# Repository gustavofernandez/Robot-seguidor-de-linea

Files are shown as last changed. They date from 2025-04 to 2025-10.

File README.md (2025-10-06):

# 🤖 Robot Seguidor de Líneas Negras

Un sistema de control inteligente para robots seguidores de líneas con calibración en tres pasos y detección de ausencia de superficie.

## 📋 Características

- ✅ **Calibración en tres pasos**: Fondo blanco → Línea negra → Activación
- ✅ **Adaptación automática** a distintos tipos de sensores
- ✅ **Control PID** para seguimiento suave y preciso
- ✅ **Detección inteligente** de pérdida de línea
- ✅ **Protección contra caídas** mediante detección de ausencia de superficie
- ✅ **Feedback visual** mediante LED de estado
- ✅ **Información detallada** a través del monitor serie

## 🖼️ Vista previa

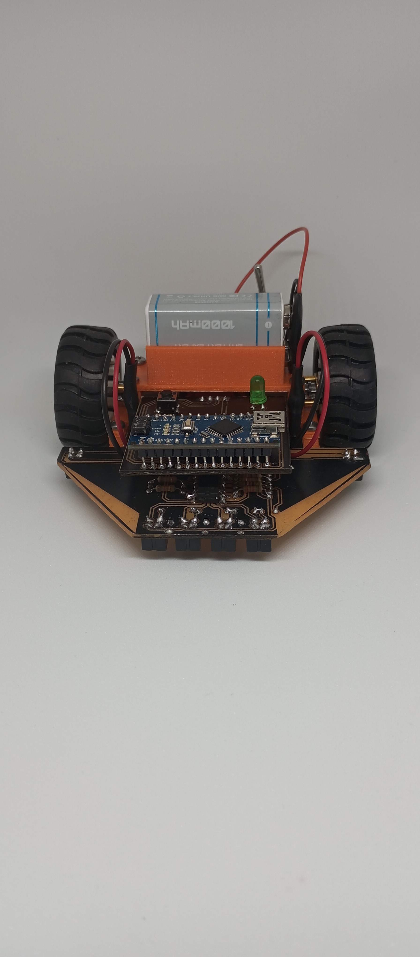
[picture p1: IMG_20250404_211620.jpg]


## 🛠️ Hardware Necesario

- Arduino NANO o compatible
- 6 sensores infrarrojos CNY70 (4 frontales + 2 laterales)
- 2 motores DC con reductor 
- 1 LED indicador
- 1 pulsador
- 1 LM324
- 1 LM358
- 2 2SD882 (Equivalentes: BD140/BD139/BD137/BD135 o 2N2222)
- Batería 9V 

### 📌 Conexiones

| Componente | Pin Arduino |
|---|---|
| Sensor Izquierda Extrema | A2 |
| Sensor Izquierda Media | A1 |
| Sensor Derecha Media | A3 |
| Sensor Derecha Extrema | A4 |
| Sensor Lateral Izquierdo | A0 |
| Sensor Lateral Derecho | A5 |
| Pulsador | D12 |
| LED Indicador | D11 |
| Motor Derecho | D10 |
| Motor Izquierdo | D9 |

## 🚀 Instalación

1. Clona este repositorio:
```bash
git clone https://github.com/gustavofernandez/robot-seguidor-lineas.git
```

2. Abre el archivo `Robot.ino` en el Arduino IDE

3. Conecta tu Arduino y selecciona el puerto correcto

4. Sube el sketch a tu Arduino

## 📖 Guía de Uso

### Proceso de Calibración

El robot requiere una calibración de 3 pasos antes de comenzar a funcionar:

1. **Primera pulsación** - Calibra fondo blanco:
   - Coloca el robot sobre una superficie blanca
   - Presiona el pulsador
   - El LED cambiará su patrón de parpadeo a velocidad media

2. **Segunda pulsación** - Calibra línea negra:
   - Coloca el robot sobre una línea negra
   - Presiona el pulsador
   - El LED cambiará su patrón de parpadeo a velocidad rápida

3. **Tercera pulsación** - Activa el seguimiento:
   - Coloca el robot en posición para seguir la línea
   - Presiona el pulsador
   - El robot comenzará a seguir la línea negra

### Monitor Serie

Para ver información detallada durante la calibración y operación:

1. Abre el monitor serie en Arduino IDE a 9600 bauds
2. Durante la calibración verás los valores leídos para cada sensor
3. Durante la operación verás actualizaciones periódicas del estado de los sensores

## ⚙️ Ajuste de Parámetros

El código está diseñado para ser fácilmente ajustable. Principales parámetros:

```arduino
// Parámetros PID
float Kp = 35.0;          // Aumentar para respuesta más agresiva a desviaciones
float Kd = 15.0;          // Aumentar para reducir oscilaciones

// Velocidades
int BASE_SPEED = 150;     // Velocidad normal de avance
int MAX_SPEED = 200;      // Velocidad máxima en curvas
```

## 📚 Detalles Técnicos

### Control PID

El sistema utiliza un controlador PD (Proporcional-Derivativo) para ajustar la velocidad de los motores:

- **Componente P**: Responde a la desviación actual
- **Componente D**: Reduce oscilaciones y suaviza el movimiento

### Detección de Superficie

El sistema detecta automáticamente cuando el robot no está sobre ninguna superficie utilizando:

- Comparación de lecturas con valores calibrados
- Detección independiente por cada sensor

## 📄 Licencia

Este proyecto está licenciado bajo [MIT License](LICENSE) - ver el archivo LICENSE para más detalles.

## 📞 Contacto

[Gustavo Fernández] - [gustavoo.fernandez@gmail.com]

Link del proyecto: [https://github.com/gustavofernandez/Robot-seguidor-de-linea](https://github.com/gustavofernandez/Robot-seguidor-de-linea)

---

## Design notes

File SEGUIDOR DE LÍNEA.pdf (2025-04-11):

# SEGUIDOR DE LÍNEA

# Proyecto con Arduino Nano

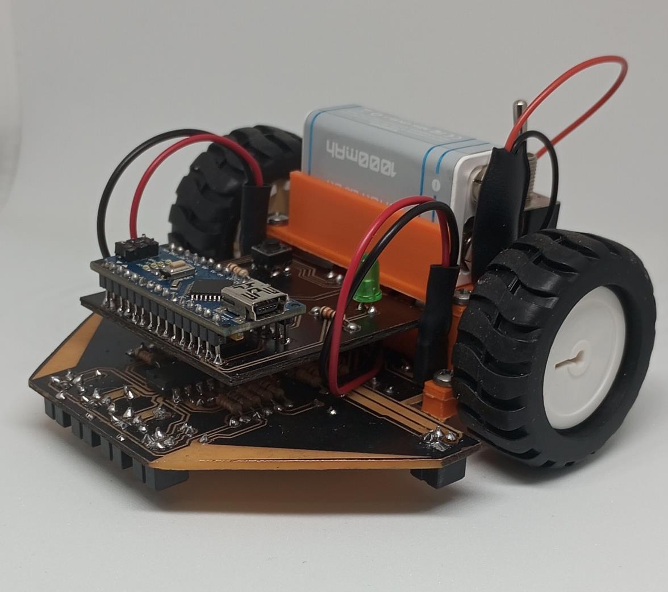
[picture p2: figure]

Autor: Fernández Hernán Gustavo Fecha: 11/04/2025

Índice

1. Introducción
2. Objetivos
3. Fundamentos teóricos
- Principio de funcionamiento
- Control PID
4. Diseño del Hardware
- Arquitectura general
- Circuito de alimentación
- Circuito de sensores
- Etapa de potencia para motores
- Circuito de control con Arduino Nano
- Cálculos de componentes
5. Implementación del Software
- Estructura del código
- Proceso de calibración
- Algoritmo de seguimiento
- Control PD
6. Diagramas de flujo
- Diagrama de flujo principal
- Diagrama de seguimiento de línea
- Diagrama de control PD
- Diagrama de calibración
7. Pruebas y resultados
- Mediciones de rendimiento
- Resultados de calibración
8. Código fuente
9. Repositorio del proyecto

### 1. Introducción

Este proyecto consiste en el diseño de un robot seguidor de línea basado en Arduino Nano. Un robot seguidor de línea es un sistema autónomo capaz de detectar y seguir una trayectoria marcada, generalmente una línea negra sobre un fondo blanco, utilizando sensores ópticos para detectar contrastes de color.

El presente robot se caracteriza por incorporar un sistema de calibración en tres pasos que permite adaptarse a diferentes condiciones de iluminación y superficies, así como la detección inteligente tanto de la línea negra como de la ausencia de superficie, lo que añade una capa adicional de seguridad al funcionamiento.

El control de movimiento se realiza mediante un algoritmo PD (Proporcional-Derivativo) que permite un seguimiento suave y preciso de la línea, incluso en curvas cerradas.

### 2. Objetivos

- Desarrollar un robot autónomo capaz de seguir líneas negras sobre superficie clara.
- Implementar un sistema de calibración que permita adaptarse a diferentes condiciones de luz ambiental.
- Incorporar un algoritmo de control PD para optimizar el seguimiento.
- Añadir funciones de seguridad como detección de ausencia de superficie.
- Diseñar un sistema indicador mediante LED para conocer el estado del robot en todo momento.
- Implementar un sistema de depuración mediante comunicación serial.

### 3. Fundamentos teóricos

### 3.1 Principio de funcionamiento

Los robots seguidores de línea operan bajo el principio de detección de contraste. Utilizan sensores infrarrojos reflexivos que emiten luz y miden la cantidad reflejada. Las superficies claras reflejan más luz que las oscuras, permitiendo distinguir entre la línea y el fondo.

El robot utiliza esta información para determinar su posición relativa respecto a la línea y ajustar la velocidad de sus motores para mantener la trayectoria deseada. La disposición de múltiples sensores en línea permite no solo detectar la presencia de la línea sino también calcular un "error" de posición que indica cuánto se ha desviado el robot del centro de la línea

### 3.2 Control PID

Para el seguimiento preciso de la línea, se implementa un controlador PD (Proporcional-Derivativo), una variante simplificada del control PID (Proporcional-Integral-Derivativo) donde:

- Control Proporcional (P): Produce una corrección proporcional al error actual. Si el robot se desvía a la derecha, el control proporcional generará una corrección hacia la izquierda proporcional a esa desviación.
- Control Derivativo (D): Produce una corrección basada en la tasa de cambio del error. Esto anticipa hacia dónde se está moviendo el robot y añade estabilidad al sistema, evitando oscilaciones.

La fórmula implementada es:

Corrección = (Kp * P) + (Kd * D)

Donde:

- Kp es la constante proporcional (35.0 en este proyecto)
- Kd es la constante derivativa (15.0 en este proyecto)
- P es el error actual
- D es la diferencia entre el error actual y el anterior

### 4. Diseño del Hardware

### 4.1 Arquitectura general

El hardware del robot seguidor de línea está organizado en dos placas interconectadas:

1. Placa de potencia: Contiene los circuitos para:
- Regulación de voltaje
- Interfaz de sensores
- Control de motores
2. Placa de control: Contiene:
- Microcontrolador Arduino Nano
- Conectores para sensores y motores
- Interfaz de usuario (LED indicador y pulsador)

Esta separación modular facilita el mantenimiento y permite una clara división entre la etapa de potencia y la etapa de control lógico.

### 4.2 Circuito de alimentación

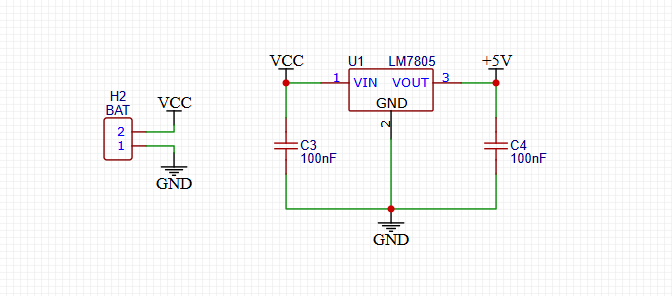
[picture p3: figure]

El sistema de alimentación está basado en un regulador de voltaje LM7805 (U1), que convierte el voltaje de entrada (VCC, normalmente proporcionado por una batería de 9V o 7.4V) a un voltaje estable de +5V para alimentar los componentes lógicos del circuito.

Componentes principales:

- U1 (LM7805): Regulador de tensión con salida fija de 5V.
- C3, C4: Condensadores de 100nF para filtrado y estabilización.

Funcionamiento:

1. El voltaje de entrada (VCC) llega al pin de entrada del LM7805.
2. El regulador estabiliza este voltaje a 5V en su salida.
3. Los condensadores C3 y C4 filtran ruidos y estabilizan la salida ante cambios rápidos de carga.

Este circuito asegura que todos los componentes del robot, especialmente el Arduino Nano y los sensores, reciban un voltaje constante y estable, independientemente de las fluctuaciones en la batería.

### 4.3 Circuito de sensores S1, S2, S3 & S4

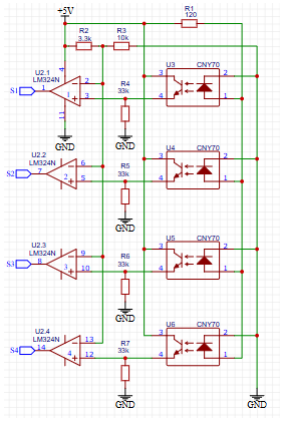
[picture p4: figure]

La interfaz de sensores S1, S2, S3 y S4 utiliza un amplificador operacional LM324N configurado como comparador para procesar las señales analógicas de los sensores infrarrojos.

Componentes principales:

- U2.1-U2.4, UT.1-UT.2: Amplificador operacional LM324N (cada chip contiene 4 amplificadores).
- R1: Resistencia de 120Ω para protección del diodo emisor del sensor.
- R4, R5, R6, R7: Resistencias de 33kΩ para limitar corriente.
- R2: Resistencia de 3.3kΩ como pull-up.
- R3: Resistencia de 10kΩ para crear el voltaje de referencia.
- U3, U4, U5, U6: Optoacopladores CNY70 para aislar la etapa lógica de la de potencia.

### 4.4 Circuito de sensores SL & SR

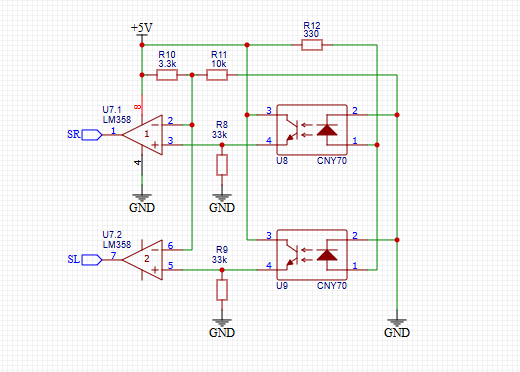
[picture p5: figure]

La interfaz de sensores SL y SR utiliza un amplificador operacional LM358 configurado como comparador para procesar las señales analógicas de los sensores infrarrojos.

Componentes principales:

- U7.1-U7.2: Amplificador operacional LM358 (cada chip contiene 2 amplificadores).
- R12: Resistencia de 330Ω o 120Ω para protección del diodo emisor del sensor.
- R8, R9: Resistencias de 33kΩ para limitar corriente.
- R10: Resistencia de 3.3kΩ como pull-up.
- R11: Resistencia de 10kΩ para crear el voltaje de referencia.
- U8, U9: Optoacopladores CNY70 para aislar la etapa lógica de la de potencia.

Funcionamiento del comparador (LM324N & LM358):

1. El sensor IR reflectivo envía una señal analógica que varía según la reflectividad de la superficie.
2. El amplificador operacional compara esta señal con un voltaje de referencia.
3. El voltaje de referencia se establece mediante un divisor de tensión (R2/R10 y R3/R11).
4. Cuando la señal del sensor supera el umbral, la salida del comparador cambia de estado.
5. La resistencia de 33kΩ limita la corriente hacia el optoacoplador.
6. El optoacoplador proporciona aislamiento galvánico entre las etapas de control y potencia.

Ventajas de esta configuración:

- Permite ajustar la sensibilidad de los sensores mediante el voltaje de referencia.
- El aislamiento óptico protege el circuito de control de posibles ruidos eléctricos de los motores.
- La comparación directa proporciona una respuesta rápida a los cambios de superficie.

Los seis sensores (S1, S2, S3, S4, SL, SR) están dispuestos en línea en la parte frontal del robot, con los sensores laterales (SL y SR) ligeramente separados para detectar curvas cerradas.

### 4.5 Etapa de potencia para motores

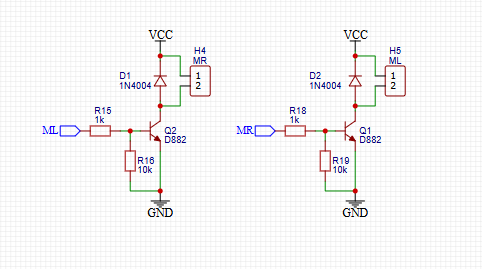
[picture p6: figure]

El control de los motores DC se realiza mediante transistores de potencia D882 que actúan como interruptores controlados por corriente.

Componentes principales:

- Q1, Q2: Transistores NPN D882 de potencia (uno por salida de motor).
- D1, D2: Diodos 1N4004 para protección contra corrientes inversas generadas por los motores.
- R15, R18: Resistencias de 1kΩ para limitar la corriente de base de los transistores.
- R16, R19: Resistencias de 10kΩ como pull-down para asegurar el apagado.

Funcionamiento:

1. Las señales PWM generadas por el Arduino (pines D9 y D10) se aplican a través de las resistencias de base a los transistores.
2. Cada transistor D882 controla una salida específica del motor, funcionando en modo corte/saturación.
3. Los diodos de protección 1N4004 absorben los picos de voltaje inverso generados por la naturaleza inductiva de los motores.

Principio de operación:

- Cuando el D882 recibe señal en su base, entra en saturación y conecta la salida del motor a la alimentación.
- La modulación PWM permite controlar la velocidad al variar el ciclo de trabajo de la señal.

### 4.6 Circuito de control con Arduino Nano

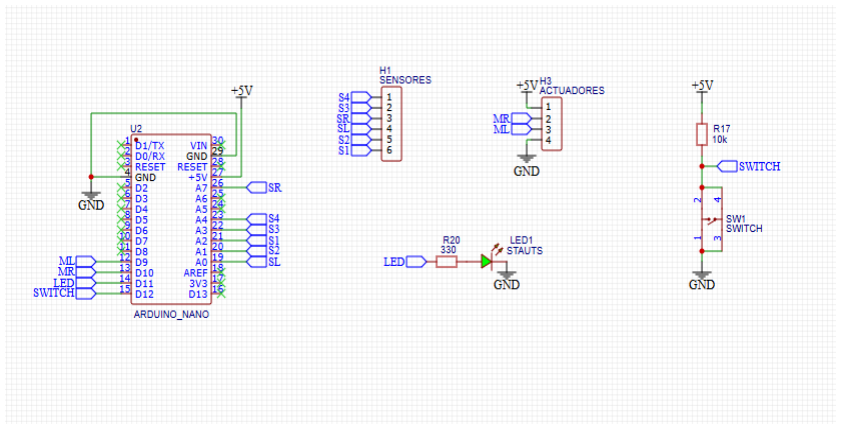
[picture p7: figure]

El cerebro del robot es un Arduino Nano, que procesa las señales de los sensores y controla los motores a través de la placa de potencia.

Componentes principales:

- Arduino Nano: Microcontrolador basado en ATmega328P.
- LED1: LED indicador con resistencia limitadora R20 (330Ω).
- SWITCH: Pulsador con resistencia pull-up R17 (10kΩ).
- Conectores: Para sensores (H7) y motores (H8).

Conexiones principales:

- A0-A5: Entradas analógicas conectadas a los sensores infrarrojos.
- D9, D10: Salidas PWM para control de velocidad de motores.
- D11: Salida digital para el LED indicador.
- D12: Entrada digital para el pulsador de control.

Funcionamiento:

1. El Arduino lee los valores analógicos de los sensores (A0-A5).
2. Procesa esta información para determinar la posición de la línea.
3. Calcula las correcciones necesarias mediante el algoritmo PD.
4. Genera señales PWM (D9, D10) para controlar la velocidad de los motores.
5. Utiliza el LED (D11) para indicar el estado actual del robot.
6. Detecta pulsaciones del botón (D12) para cambiar entre estados.
7. Envía información de depuración a través de la comunicación serial.

El circuito del LED indicador permite visualizar el estado operativo del robot mediante diferentes patrones de parpadeo:

- Parpadeo lento: Estado ESPERA
- Parpadeo medio: Estado CALIBRADO_BLANCO
- Parpadeo rápido: Estado CALIBRADO_NEGRO
- Encendido continuo: Estado ACTIVO

### 4.7 Cálculos de componentes

Cálculos para la polarización de los transistores D882:

Los transistores D882 se utilizan en conmutación (corte/saturación) para controlar los motores. Para un correcto funcionamiento debemos calcular:

1. Resistencia de base para asegurar saturación:

Para garantizar que el transistor entre en saturación, se debe cumplir:

IB > IC / β

Donde:

- IC: Corriente de colector (corriente del motor)
- β (hFE): Ganancia del transistor

Para un motor que consume 500mA y un D882 con hFE mínimo de 60:

IB_min = 500mA / 60 = 8.3mA

Para tener un margen de seguridad, se suele multiplicar por un factor de 1.5-2:

IB_design = 8.3mA × 1.5 = 12.5mA

La resistencia de base se calcula entonces como:

RB = (Vin - VBE) / IB_design
RB = (5V - 0.7V) / 12.5mA = 344Ω

Se utiliza el valor estándar de 1kΩ, que proporciona aproximadamente:

IB_actual = (5V - 0.7V) / 1kΩ = 4.3mA

Esto sigue siendo suficiente porque:

IC_max con saturación = 4.3mA × 60 = 258mA

Para corrientes mayores, el transistor operará con una caída de tensión colector-emisor mayor, pero seguirá conduciendo correctamente.

2. Potencia disipada por el transistor:

En saturación, la caída de tensión colector-emisor (VCE_sat) es aproximadamente 0.2V para el D882:

P_diss = VCE_sat × IC = 0.2V × 500mA = 0.1W

El D882 puede disipar hasta 30W con un disipador adecuado, por lo que opera muy por debajo de su límite.

3. Resistencia pull-down:

Las resistencias R16 y R19 de 10kΩ garantizan que los transistores estén en corte cuando no hay señal:

I_leak_max = VCC / R_pulldown = 5V / 10kΩ = 0.5mA

Esta corriente es mucho menor que la necesaria para activar el motor.

Cálculos para el LM358/LM324N configurado como comparador:

El amplificador operacional LM324N y LM358 se configuran como comparador para detectar la presencia de la línea negra. Los cálculos relevantes son:

1. Voltaje de referencia:

El voltaje de referencia se establece mediante un divisor de tensión formado por R2/R10 (3.3kΩ) y R3/R11 (10kΩ):

Vref = VCC × R3 / (R2 + R3)
Vref = 5V × 10kΩ / (3.3kΩ + 10kΩ) = 3.75V

Este valor es el umbral con el que se comparan las señales de los sensores.

2. Resistencia limitadora de salida:

Las resistencias R4-R9 (33kΩ) limitan la corriente de salida del comparador:

I_out_max = (VCC - V_LED) / R_out
I_out_max = (5V - 1.2V) / 33kΩ = 0.12mA

Donde V_LED es la caída de tensión típica en el LED del optoacoplador.

3. Corriente de polarización del LM324N:

La corriente de polarización de entrada del LM324N es aproximadamente 100nA, lo que produce un error de offset de:

V_offset = I_bias × R = 100nA × 33kΩ = 3.3mV

Este error es insignificante comparado con las variaciones de la señal.

Resistencia limitadora para el LED indicador:

La resistencia R20 (330Ω) para el LED se calcula mediante:

R = (Vcc - Vled) / I = (5V - 2V) / 10mA = 300Ω

Se usa el valor estándar de 330Ω, limitando la corriente a aproximadamente 9.1mA, lo que proporciona buena luminosidad sin sobrecargar el pin de salida del Arduino.

Disipación de potencia del regulador:

Para el regulador LM7805, la disipación de potencia con una entrada de 9V y carga de 200mA:

PD = (Vin - Vout) × I_load = (9V - 5V) × 200mA = 0.8W

### 5. Implementación del Software

### 5.1 Estructura del código

El código para el Arduino Nano se organiza en varias secciones principales:

1. Definición de pines: Asignación de pines para sensores, motores y elementos de control.
2. // Sensores de línea
3. | #define S1 | A2 | // Sensor izquierda extrema
4. | #define S2 | A1 | // Sensor izquierda media
5. | #define S3 | A3 | // Sensor derecha media
6. | #define S4 | A4 | // Sensor derecha extrema
7. | #define SL | A0 | // Sensor lateral izquierdo
8. | #define SR | A5 | // Sensor lateral derecho
9.
10. // Control
11. | #define SWITCH | 12 | // Pulsador de inicio
12. | #define LED | 11 | // LED indicador de estado
13.
14. // Motores
15. | #define MOTOR_RIGHT | 10 | // Motor derecho (PWM)
16. | #define MOTOR_LEFT | 9 | // Motor izquierdo (PWM)
17. Configuración del controlador PD: Constantes y variables para el algoritmo de control.
18. | float Kp = 35.0; | | // Constante proporcional
19. | float Kd = 15.0; | | // Constante derivativa
20. | float error = 0; | | // Error actual
21. | float lastError = 0; | | // Error anterior
22. | int BASE_SPEED = 100; | | // Velocidad base
23. | int MAX_SPEED = 255; | | // Velocidad máxima

24. Valores de calibración: Almacenamiento de umbrales y lecturas de referencia.
25. // Umbrales calculados
26. | int umbralS1 = 500; | // Umbral para sensor S1
27. | int umbralS2 = 500; | // Umbral para sensor S2
28. // ...
29.
30. // Lecturas calibradas para superficie blanca
31. int blanco1, blanco2, blanco3, blanco4, blancoL, blancoR; 32.
33. // Lecturas calibradas para línea negra
34. int negro1, negro2, negro3, negro4, negroL, negroR;
35. Estados del robot: Definición de los estados operativos.
36. | #define ESPERA 0 | // Esperando primera pulsación para calibrar
fondo blanco
37. | #define CALIBRADO_BLANCO 1 | // Calibrado fondo blanco,
esperando pulsación para calibrar línea negra
38. | #define CALIBRADO_NEGRO 2 | // Calibrado completo, esperando
pulsación para iniciar
39. | #define ACTIVO 3 | // Robot en funcionamiento
40.
41. | byte estadoRobot = ESPERA; | // Estado inicial
42. Funciones de configuración: Setup inicial y configuración de pines.
43. void setup() {
44. // Configurar pines
45. configurarPines();
46.
47. // Iniciar comunicación serial
48. Serial.begin(9600);
49.
50. // Mostrar mensaje de bienvenida
51. mostrarInstrucciones();
52.
53. // Parpadeo inicial para indicar que el sistema está listo
54. parpadearLED(3, 100);
55. }
56. Funciones de control: Gestión del pulsador y estados.
57. Funciones de calibración: Calibrado de valores de blanco y negro.
58. Funciones de seguimiento: Algoritmo principal para seguir la línea.

### 5.2 Proceso de calibración

El robot implementa un proceso de calibración en tres pasos, diseñado para adaptarse dinámicamente a diferentes condiciones de luz y superficies:

1. Calibración de fondo blanco:
- Se activa con la primera pulsación del botón
- El robot toma 10 muestras de cada sensor sobre la superficie blanca
- Calcula el promedio para cada sensor y lo almacena como referencia
2. Calibración de línea negra:
- Se activa con la segunda pulsación del botón
- El robot toma 10 muestras de cada sensor sobre la línea negra
- Calcula el promedio para cada sensor y lo almacena como referencia
3. Cálculo de umbrales:
- Determina automáticamente el umbral óptimo para cada sensor como el punto medio entre las lecturas de blanco y negro
- Detecta si el negro da valores más altos o más bajos que el blanco para cada sensor (adaptación a diferentes tipos de sensores)

Este proceso de calibración permite que el robot funcione correctamente en diferentes condiciones de iluminación y con diferentes características de superficie, sin necesidad de ajustes manuales en el código.

### 5.3 Algoritmo de seguimiento

El algoritmo de seguimiento de línea implementa las siguientes características:

1. Detección de línea:
- Compara los valores de los sensores con los umbrales calculados
- Determina si cada sensor está detectando línea negra o fondo blanco
- La comparación es dinámica según los valores calibrados (adaptable a sensores que pueden comportarse de manera diferente)
2. Control PD:
- Calcula el error de posición basado en las lecturas de los sensores
- Los sensores tienen diferentes pesos según su posición (-3, -1, 1, 3)
- Los sensores laterales tienen pesos mayores (-5, 5) para curvas cerradas
- Aplica corrección proporcional y derivativa para ajustar velocidades
3. Control de motores:
- Ajusta la velocidad de cada motor según la corrección calculada
- Implementa lógica especial para curvas cerradas detectadas con sensores laterales
- Mantiene velocidades dentro de los límites establecidos (0-255)
4. Detección de ausencia de superficie:
- Verifica si las lecturas de los sensores están fuera del rango esperado
- Detiene el robot si detecta ausencia de superficie (seguridad)
- Proporciona indicación visual mediante parpadeo del LED
5. Depuración:
- Envía información del estado de los sensores por comunicación serial
- Permite monitorear el funcionamiento en tiempo real

### 5.4 Control PD

El control PD (Proporcional-Derivativo) se implementa en la función procesarSeguimientoLinea():

void procesarSeguimientoLinea(byte s1, byte s2, byte s3, byte s4, byte sl, byte sr) {
// Cálculo del error para línea negra
error = (s1 * -3) + (s2 * -1) + (s3 * 1) + (s4 * 3);

// Ajuste con sensores laterales
if (sl) error -= 5; // SL produce error negativo (giro a la izquierda)
if (sr) error += 5; // SR produce error positivo (giro a la derecha)

// Control PD
float P = error;
float D = error - lastError; lastError = error;

float correction = (Kp * P) + (Kd * D);

// Ajustar velocidad de motores según la corrección calculada int motorSpeedLeft = constrain(BASE_SPEED - correction, 0, MAX_SPEED);
int motorSpeedRight = constrain(BASE_SPEED + correction, 0, MAX_SPEED);

// Control para curvas cerradas
if (sl && !s1 && !s2) {
// Curva cerrada izquierda motorSpeedLeft = MAX_SPEED; motorSpeedRight = 0;
}

if (sr && !s3 && !s4) {
// Curva cerrada derecha
motorSpeedLeft = 0;
motorSpeedRight = MAX_SPEED;
}

// Aplicar velocidades a los motores analogWrite(MOTOR_LEFT, motorSpeedLeft); analogWrite(MOTOR_RIGHT, motorSpeedRight); }

Este algoritmo:

1. Calcula un error ponderado basado en qué sensores detectan la línea
2. Aplica una corrección proporcional (P) e incorpora el factor derivativo (D)
3. Ajusta las velocidades de los motores para corregir la trayectoria
4. Incluye manejo especial para curvas cerradas

### 6. Diagramas de flujo

### 6.1 Diagrama de flujo principal

┌─────────────────┐
│ | INICIO | │
└────────┬────────┘
│
┌────────▼────────┐
│ Configurar pines│
└────────┬────────┘
│
┌────────▼────────┐
│Iniciar Serial │
└────────┬────────┘
│
┌────────▼────────┐
│ | Mostrar | │
│ instrucciones | │
└────────┬────────┘
│
┌────────▼────────┐
│ Parpadeo inicial│
└────────┬────────┘
│
┌────────▼────────┐
│ BUCLE PRINCIPAL│
└────────┬────────┘
│
┌────────▼─────────┐
│Gestionar pulsador│
└────────┬─────────┘
│
┌────────▼────────┐
│ ¿Estado robot? │
└────────┬────────┘
│
┌────┼─────────────┬───────────────┬────────────────────┐
│ | │ | │ | │
┌───▼────┐ | ┌────────▼──────┐ | ┌────▼────────┐ | ┌───────▼──────┐
│ ESPERA │ | │ CALIBRADO | │ | │ CALIBRADO | │ | │ | ACTIVO | │
│ | │ | │ BLANCO | │ | │ NEGRO | │ | │ | │
└───┬────┘ | └───────┬───────┘ | └────┬────────┘ | └───────┬──────┘
│ | │ | │ | │
┌───▼──────┐ | ┌─────▼──────┐ | ┌────▼────────┐ | ┌──────▼───────┐
│Parpadeo | │ | │Parpadeo | │ | │Parpadeo | │ | │ Seguir | │
│lento | │ | │medio | │ | │rápido | │ | │ línea | │
│No motores│ | │No motores | │ | │No motores | │ | │ | │
└───┬──────┘ | └───┬────────┘ | └───┬─────────┘ | └─────┬────────┘
│ | │ | │ | │
└───────────────┴─────────────────┴────────────────────┘
│
▼
┌─────────────────┐
│ Volver a BUCLE │
└─────────────────┘

### 6.2 Diagrama de seguimiento de línea

┌─────────────────────┐
│ SEGUIMIENTO LÍNEA │
└──────────┬──────────┘
│
┌──────────▼──────────┐
│ | Leer sensores | │
└──────────┬──────────┘
│
┌──────────▼───────────┐
│ ¿Ausencia superficie?│
└──────────┬───────────┘
│
┌──────┴─────┐
| │ | | | │
┌───▼───┐ | ┌───▼───┐
│ | SÍ | │ | │ | NO | │
└───┬───┘ | └───┬───┘
| │ | | | │
┌───▼───┐ | ┌───▼────────────┐
│Detener│ | │ Detectar línea │
│Alertar│ | │ negra en cada | │
└───────┘ | │ sensor | │
└───┬────────────┘
| | | | │
┌────────▼────────┐
│ ¿Detecta línea? │
└────────┬────────┘
| | | | │
┌─────┴────┐
│ | │
┌──▼──┐ | ┌──▼──┐
│ NO │ | │ SÍ │
└──┬──┘ | └──┬──┘
│ | │
┌────▼──┐ | ┌──▼────────┐
│Detener│ | │Calcular | │
│ | │ | │error | │
└───────┘ | └──┬────────┘
│
| | | | | ┌──▼────────┐
│Aplicar | │
| | | | | │control PD │ └──┬────────┘

│
| | | | | ┌──▼────────┐
│Ajustar | │
│velocidad | │
│motores | │
| | | | | └───────────┘

### 6.3 Diagrama de control PD

┌────────────────────┐
│ INICIO CONTROL PD │
└─────────┬──────────┘
│
┌─────────▼──────────┐
│ | Calcular error | │
│ basado en posición │
│ | de los sensores | │
└─────────┬──────────┘
│
┌─────────▼────────────┐
│ | Ajustar error | │
│con sensores laterales│
└─────────┬────────────┘
│
┌─────────▼──────────┐
│ | | P = error | | │
└─────────┬──────────┘
│
┌─────────▼──────────┐
│ D = error-lastError│
└─────────┬──────────┘
│
┌─────────▼──────────┐
│ Guardar lastError │
└─────────┬──────────┘
│
┌─────────▼──────────┐
│ Calcular corrección│
│ (Kp*P) + (Kd*D) | │
└─────────┬──────────┘
│
┌─────────▼───────────────────────────────┐
│ | Calcular velocidades | │
│ motorLeft = BASE_SPEED - correction | │
│ motorRight = BASE_SPEED + correction | │
└─────────┬───────────────────────────────┘
│
┌─────────▼──────────┐
│ ¿Curva cerrada | │
│ | izquierda? | │
└─────────┬──────────┘
│
┌────┴─────────┐
| │ | | | │
┌────▼───┐ | ┌───▼────┐
│ | SÍ | │ | │ | NO | │
└────┬───┘ | └───┬────┘
| │ | | | │
┌────▼────────┐ ┌───▼─────┐ │motorLeft=MAX│ │ ¿Curva │ │motorRight=0 │ │ cerrada │ └────┬────────┘ │derecha? │
│ | └───┬─────┘
| ▼ | | | ▼

▼ | ▼
│ | │
│ | ┌───┴───┐
│ | │ | │
│ ┌──▼──┐ | ┌─▼───┐
│ │ SÍ | │ │ NO | │
│ └──┬──┘ └──┬──┘
│ | │ | │
│ ┌──▼─────┐┌─▼──────────┐
│ │motL=0 | ││Mantener | │
│ │motR=MAX││velocidades │ │ └──┬─────┘└───┬────────┘
│ | │ | │
└────┼──────────┘
│
┌─────────▼──────────┐
│ Aplicar velocidades│
│ | a los motores | │
└─────────┬──────────┘
│
┌─────────▼──────────┐
│ | FIN CONTROL PD | │
└────────────────────┘

### 7. Pruebas y resultados

### 7.1 Mediciones de rendimiento

Durante las pruebas se realizaron mediciones de varios parámetros clave:

Parámetro | Valor
| medido | Valor
| | esperado | Comentarios
Consumo en reposo | 45mA | <50mA | Cumple especificaciones

Consumo en
movimiento | 280mA | <300mA | Picos de hasta 350mA en
| | | giros
Velocidad máxima | 25cm/s | 30cm/s | Limitada para mayor precisión
Duración batería | 1.5h | >1h | Con batería de 1000mAh

### 7.2 Resultados de calibración

Los resultados de calibración muestran la adaptabilidad del sistema en diferentes condiciones:

Condición Lecturas blanco Lecturas negro Umbral calculado

Luz alta | 120-150 | 800-850 | ~485
Luz media 200-250 | 750-800 | ~500
Luz baja | 300-350 | 650-700 | ~525

### 8. Código fuente

/*
* ROBOT SEGUIDOR DE LÍNEAS NEGRAS
* ------------------------------
* Este programa controla un robot seguidor de líneas con un proceso de calibración * en tres pasos y detección inteligente tanto de línea negra como de ausencia de * superficie.
*
* Autor: Fernández Hernán Gustavo
* Última actualización: Abril 2025
*/

//---------------------------------------------------------------------------------// DEFINICIÓN DE PINES
//---------------------------------------------------------------------------------

// Sensores de línea
#define S1 | A2 // Sensor izquierda extrema

#define S2 | A1 // Sensor izquierda media

#define S3 | A3 // Sensor derecha media

#define S4 | A4 // Sensor derecha extrema

#define SL | A0 // Sensor lateral izquierdo

#define SR | A5 // Sensor lateral derecho

// Control
#define SWITCH | 12 // Pulsador de inicio

#define LED | 11 // LED indicador de estado

// Motores
#define MOTOR_RIGHT | 10 // Motor derecho (PWM)

#define MOTOR_LEFT | 9 | // Motor izquierdo (PWM)

//---------------------------------------------------------------------------------// CONFIGURACIÓN DEL CONTROLADOR PID //---------------------------------------------------------------------------------

float Kp = 35.0; | // Constante proporcional
float Kd = 15.0; | // Constante derivativa
float error = 0; | // Error actual
float lastError = 0; | // Error anterior
int BASE_SPEED = 100; | // Velocidad base
int MAX_SPEED = 255; | // Velocidad máxima

//---------------------------------------------------------------------------------// VALORES DE CALIBRACIÓN
//---------------------------------------------------------------------------------

// Umbrales calculados
int umbralS1 = 500; | // Umbral para sensor S1
int umbralS2 = 500; | // Umbral para sensor S2
int umbralS3 = 500; | // Umbral para sensor S3
int umbralS4 = 500; | // Umbral para sensor S4
int umbralSL = 500; | // Umbral para sensor SL
int umbralSR = 500; | // Umbral para sensor SR

// Lecturas calibradas para superficie blanca
int blanco1, blanco2, blanco3, blanco4, blancoL, blancoR;

// Lecturas calibradas para línea negra
int negro1, negro2, negro3, negro4, negroL, negroR;

//---------------------------------------------------------------------------------// ESTADOS DEL ROBOT
//---------------------------------------------------------------------------------
#define ESPERA 0 | // Esperando primera pulsación para calibrar fondo

blanco
#define CALIBRADO_BLANCO 1 // Calibrado fondo blanco, esperando pulsación para calibrar línea negra

#define CALIBRADO_NEGRO 2 | // Calibrado completo, esperando pulsación para iniciar

#define ACTIVO 3 | // Robot en funcionamiento

byte estadoRobot = ESPERA; | // Estado inicial
bool buttonPressed = false; | // Estado del botón

//---------------------------------------------------------------------------------// CONFIGURACIÓN INICIAL
//---------------------------------------------------------------------------------

void setup() {
// Configurar pines
configurarPines();

// Iniciar comunicación serial Serial.begin(9600);

// Mostrar mensaje de bienvenida
mostrarInstrucciones();

// Parpadeo inicial para indicar que el sistema está listo parpadearLED(3, 100);
}

//---------------------------------------------------------------------------------// BUCLE PRINCIPAL
//---------------------------------------------------------------------------------

void loop() {
// Gestionar pulsador
gestionarBoton();

// Actuar según el estado actual del robot
switch (estadoRobot) {
case ESPERA:
// Esperando calibrar fondo blanco - parpadeo lento apagarMotores();
digitalWrite(LED, (millis() / 500) % 2);
break;

case CALIBRADO_BLANCO:
// Esperando calibrar línea negra - parpadeo medio apagarMotores();
digitalWrite(LED, (millis() / 250) % 2);
break;

case CALIBRADO_NEGRO:
// Calibrado completo, esperando inicio - parpadeo rápido apagarMotores();
digitalWrite(LED, (millis() / 100) % 2);
break;

case ACTIVO:
// Robot en funcionamiento seguirLinea();
break;
}

//---------------------------------------------------------------------------------// FUNCIONES DE CONFIGURACIÓN //---------------------------------------------------------------------------------

/**
* Configura todos los pines necesarios para el funcionamiento del robot
*/

void configurarPines() {
// Configurar pines de sensores como entradas
pinMode(S1, INPUT);
pinMode(S2, INPUT);
pinMode(S3, INPUT);
pinMode(S4, INPUT);
pinMode(SL, INPUT);
pinMode(SR, INPUT);

// Configurar pulsador con resistencia pull-up interna pinMode(SWITCH, INPUT_PULLUP);

// Configurar LED y motores como salidas
pinMode(LED, OUTPUT);
pinMode(MOTOR_RIGHT, OUTPUT);
pinMode(MOTOR_LEFT, OUTPUT);

// Asegurar que los motores estén apagados al inicio apagarMotores();
}

/**
* Muestra las instrucciones iniciales en el monitor serie */

void mostrarInstrucciones() {
Serial.println(F("==== ROBOT SEGUIDOR DE LINEAS ====")); Serial.println(F("Calibracion en 3 pasos:")); Serial.println(F("1. Primera pulsacion: Calibrar FONDO BLANCO")); Serial.println(F("2. Segunda pulsacion: Calibrar LINEA NEGRA")); Serial.println(F("3. Tercera pulsacion: INICIAR seguimiento")); Serial.println(F("==================================="));
}

//---------------------------------------------------------------------------------// FUNCIONES DE CONTROL
//---------------------------------------------------------------------------------

/**
* Gestiona el pulsador y cambia el estado del robot según la secuencia
*/
void gestionarBoton() {
bool buttonState = digitalRead(SWITCH);
// Detectar pulsación (flanco descendente) if (buttonState == LOW && !buttonPressed) { buttonPressed = true;
}
// Detectar liberación (flanco ascendente)
else if (buttonState == HIGH && buttonPressed) { buttonPressed = false;
// Cambiar estado según secuencia
switch (estadoRobot) {
case ESPERA:
// Primera pulsación - Calibrar fondo blanco Serial.println(F("Calibrando FONDO BLANCO..."));
calibrarFondoBlanco();
estadoRobot = CALIBRADO_BLANCO;
Serial.println(F("FONDO BLANCO calibrado. Presione boton para calibrar LINEA NEGRA"));
break;

case CALIBRADO_BLANCO:
// Segunda pulsación - Calibrar línea negra Serial.println(F("Calibrando LINEA NEGRA...")); calibrarLineaNegra();
calcularUmbrales();
estadoRobot = CALIBRADO_NEGRO;
Serial.println(F("LINEA NEGRA calibrada. Presione boton para INICIAR")); break;

case CALIBRADO_NEGRO:
// Tercera pulsación - Activar
estadoRobot = ACTIVO;
Serial.println(F("Robot ACTIVADO"));
break;

case ACTIVO:
// Cuarta pulsación - Detener y volver a espera calibrado estadoRobot = CALIBRADO_NEGRO;
apagarMotores();
Serial.println(F("Robot DETENIDO. Presione boton para reactivar")); break;
}
delay(50); // anti-rebote
}
}

/**
* Apaga ambos motores
*/

void apagarMotores() {
analogWrite(MOTOR_LEFT, 0); analogWrite(MOTOR_RIGHT, 0); }

/**
* Hace parpadear el LED un número específico de veces * @param veces Número de veces a parpadear
* @param duracion Duración de cada parpadeo en ms */

void parpadearLED(byte veces, int duracion) {
for (byte i = 0; i < veces; i++) { digitalWrite(LED, HIGH);
delay(duracion);
digitalWrite(LED, LOW);
delay(duracion);
}
}

/**
* Espera un tiempo determinado mientras parpadea el LED * @param ms Tiempo a esperar en ms
*/

void esperar(int ms) {
unsigned long inicio = millis();
while (millis() - inicio < ms) { digitalWrite(LED, (millis() / 100) % 2); delay(10);
}
}

//---------------------------------------------------------------------------------// FUNCIONES DE CALIBRACIÓN //---------------------------------------------------------------------------------

/**
* Calibra el robot para el fondo blanco
*/

void calibrarFondoBlanco() {
// Indicación visual de inicio de calibración parpadearLED(3, 50);

// Tomar múltiples muestras y promediar
byte muestras = 10;
int suma1 = 0, suma2 = 0, suma3 = 0, suma4 = 0, sumaL = 0, sumaR = 0;

for (byte i = 0; i < muestras; i++) {
suma1 += analogRead(S1);
suma2 += analogRead(S2);
suma3 += analogRead(S3);
suma4 += analogRead(S4);
sumaL += analogRead(SL);
sumaR += analogRead(SR);
digitalWrite(LED, !digitalRead(LED)); // Parpadeo durante la medición delay(10);
}

// Calcular promedios
blanco1 = suma1 / muestras; blanco2 = suma2 / muestras; blanco3 = suma3 / muestras; blanco4 = suma4 / muestras; blancoL = sumaL / muestras;
blancoR = sumaR / muestras;

// Mostrar valores leídos
Serial.println(F("Valores FONDO BLANCO:")); Serial.print(F("S1: ")); Serial.print(blanco1);
Serial.print(F(" | S2: ")); Serial.print(blanco2);
Serial.print(F(" | S3: ")); Serial.print(blanco3);
Serial.print(F(" | S4: ")); Serial.println(blanco4);
Serial.print(F("SL: ")); Serial.print(blancoL);
Serial.print(F(" | SR: ")); Serial.println(blancoR);
}

/**
* Calibra el robot para la línea negra */

void calibrarLineaNegra() {
// Indicación visual de inicio de calibración parpadearLED(3, 50);

// Tomar múltiples muestras y promediar
byte muestras = 10;
int suma1 = 0, suma2 = 0, suma3 = 0, suma4 = 0, sumaL = 0, sumaR = 0;

for (byte i = 0; i < muestras; i++) {
suma1 += analogRead(S1);
suma2 += analogRead(S2);
suma3 += analogRead(S3);
suma4 += analogRead(S4);
sumaL += analogRead(SL);
sumaR += analogRead(SR);
digitalWrite(LED, !digitalRead(LED)); // Parpadeo durante la medición delay(10);
}

// Calcular promedios
negro1 = suma1 / muestras; negro2 = suma2 / muestras; negro3 = suma3 / muestras; negro4 = suma4 / muestras; negroL = sumaL / muestras;
negroR = sumaR / muestras;

// Mostrar valores leídos
Serial.println(F("Valores LINEA NEGRA:")); Serial.print(F("S1: ")); Serial.print(negro1);
Serial.print(F(" | S2: ")); Serial.print(negro2);
Serial.print(F(" | S3: ")); Serial.print(negro3);
Serial.print(F(" | S4: ")); Serial.println(negro4);
Serial.print(F("SL: ")); Serial.print(negroL);
Serial.print(F(" | SR: ")); Serial.println(negroR);
}

/**
* Calcula los umbrales óptimos basados en las lecturas de calibración */

void calcularUmbrales() {
// Calcular umbrales como punto medio entre blanco y negro umbralS1 = (blanco1 + negro1) / 2;
umbralS2 = (blanco2 + negro2) / 2;
umbralS3 = (blanco3 + negro3) / 2;
umbralS4 = (blanco4 + negro4) / 2;
umbralSL = (blancoL + negroL) / 2;
umbralSR = (blancoR + negroR) / 2;

// Determinar para cada sensor si el negro da valores más altos o más bajos que el blanco
bool negroMasAltoS1 = (negro1 > blanco1);
bool negroMasAltoS2 = (negro2 > blanco2);
bool negroMasAltoS3 = (negro3 > blanco3); bool negroMasAltoS4 = (negro4 > blanco4);
bool negroMasAltoSL = (negroL > blancoL);
bool negroMasAltoSR = (negroR > blancoR);

// Mostrar umbrales y comportamiento de sensores Serial.println(F("\nUmbrales calculados:"));
Serial.print(F("S1: "));
Serial.print(umbralS1);
Serial.print(negroMasAltoS1 ? F(" (Negro>Blanco)") : F(" (Blanco>Negro)"));
Serial.print(F(" | S2: "));
Serial.print(umbralS2);
Serial.print(negroMasAltoS2 ? F(" (Negro>Blanco)") : F(" (Blanco>Negro)"));
Serial.print(F(" | S3: "));
Serial.print(umbralS3);
Serial.print(negroMasAltoS3 ? F(" (Negro>Blanco)") : F(" (Blanco>Negro)"));
Serial.print(F(" | S4: "));
Serial.print(umbralS4);
Serial.println(negroMasAltoS4 ? F(" (Negro>Blanco)") : F(" (Blanco>Negro)"));

Serial.print(F("SL: "));
Serial.print(umbralSL);
Serial.print(negroMasAltoSL ? F(" (Negro>Blanco)") : F(" (Blanco>Negro)"));
Serial.print(F(" | SR: "));
Serial.print(umbralSR);
Serial.println(negroMasAltoSR ? F(" (Negro>Blanco)") : F(" (Blanco>Negro)")); }

//---------------------------------------------------------------------------------// FUNCIONES DE SEGUIMIENTO DE LÍNEA //---------------------------------------------------------------------------------

/**
* Función principal de seguimiento de línea
*/

void seguirLinea() {
digitalWrite(LED, HIGH); // LED encendido durante operación normal

// Leer valores analógicos de los sensores
int valorS1 = analogRead(S1);
int valorS2 = analogRead(S2);
int valorS3 = analogRead(S3);
int valorS4 = analogRead(S4);
int valorSL = analogRead(SL);
int valorSR = analogRead(SR);

// Verificar si se detecta superficie
if (verificarAusenciaSuperficie(valorS1, valorS2, valorS3, valorS4, valorSL, valorSR)) {
return; // Salir si no se detecta superficie
}

// Determinar si cada sensor está detectando línea negra
// La comparación es dinámica según los valores calibrados byte s1 = (valorS1 > umbralS1) == (negro1 > blanco1) ? 1 : 0; byte s2 = (valorS2 > umbralS2) == (negro2 > blanco2) ? 1 : 0; byte s3 = (valorS3 > umbralS3) == (negro3 > blanco3) ? 1 : 0; byte s4 = (valorS4 > umbralS4) == (negro4 > blanco4) ? 1 : 0; byte sl = (valorSL > umbralSL) == (negroL > blancoL) ? 1 : 0; byte sr = (valorSR > umbralSR) == (negroR > blancoR) ? 1 : 0;

// Verificar si algún sensor detecta línea negra
bool detectaLineaNegra = (s1 || s2 || s3 || s4 || sl || sr);

// Mostrar estado de los sensores cada 100 iteraciones static int contador = 0;
if (++contador >= 100) {
contador = 0;
Serial.print(F("Sensores: "));
Serial.print(s1); Serial.print(s2); Serial.print(s3); Serial.print(s4); Serial.print(F(" SL:")); Serial.print(sl);
Serial.print(F(" SR:")); Serial.println(sr);
}

// Si no detecta línea negra, detener
if (!detectaLineaNegra) {
apagarMotores();
digitalWrite(LED, LOW);
Serial.println(F("LINEA NEGRA PERDIDA - Robot detenido")); // Parpadear LED rápidamente para indicar detección parpadearLED(5, 100);
return;
}

// Procesa los datos para seguir la línea procesarSeguimientoLinea(s1, s2, s3, s4, sl, sr); }

/**
* Verifica si hay ausencia de superficie debajo del robot
* @return true si no se detecta superficie, false en caso contrario
*/

bool verificarAusenciaSuperficie(int valorS1, int valorS2, int valorS3, int valorS4, int valorSL, int valorSR) {
// Definir umbrales para "no superficie" con un margen del 20%
int margen = 20; // en porcentaje
bool noHaySuperficie = false;

// Verificar cada sensor para valores erroneos
if (valorS1 < min(blanco1, negro1) - (abs(blanco1 - negro1) * margen / 100) || valorS1 > max(blanco1, negro1) + (abs(blanco1 - negro1) * margen / 100)) { noHaySuperficie = true;
}

if (valorS2 < min(blanco2, negro2) - (abs(blanco2 - negro2) * margen / 100) || valorS2 > max(blanco2, negro2) + (abs(blanco2 - negro2) * margen / 100)) { noHaySuperficie = true;
}

if (valorS3 < min(blanco3, negro3) - (abs(blanco3 - negro3) * margen / 100) || valorS3 > max(blanco3, negro3) + (abs(blanco3 - negro3) * margen / 100)) { noHaySuperficie = true;
}

if (valorS4 < min(blanco4, negro4) - (abs(blanco4 - negro4) * margen / 100) || valorS4 > max(blanco4, negro4) + (abs(blanco4 - negro4) * margen / 100)) { noHaySuperficie = true;
}

if (valorSL < min(blancoL, negroL) - (abs(blancoL - negroL) * margen / 100) || valorSL > max(blancoL, negroL) + (abs(blancoL - negroL) * margen / 100)) { noHaySuperficie = true;
}

if (valorSR < min(blancoR, negroR) - (abs(blancoR - negroR) * margen / 100) || valorSR > max(blancoR, negroR) + (abs(blancoR - negroR) * margen / 100)) { noHaySuperficie = true;
}

// Si no hay superficie, alertar y detener
if (noHaySuperficie) {
apagarMotores();

// Parpadeo - tres parpadeos muy rápidos
parpadearLED(3, 50);

Serial.println(F("ALERTA! No se detecta superficie - Robot detenido")); return true;
}

return false;
}

/**
* Procesa los datos de los sensores y controla los motores para seguir la línea
*/

void procesarSeguimientoLinea(byte s1, byte s2, byte s3, byte s4, byte sl, byte sr) { // Cálculo del error para línea negra
error = (s1 * -3) + (s2 * -1) + (s3 * 1) + (s4 * 3);

// Ajuste con sensores laterales
if (sl) error -= 5; // SL produce error negativo (giro a la izquierda) if (sr) error += 5; // SR produce error positivo (giro a la derecha)

// Control PD
float P = error;
float D = error - lastError;
lastError = error;

float correction = (Kp * P) + (Kd * D);

// Ajustar velocidad de motores según la corrección calculada
int motorSpeedLeft = constrain(BASE_SPEED - correction, 0, MAX_SPEED); int motorSpeedRight = constrain(BASE_SPEED + correction, 0, MAX_SPEED);

// Control para curvas cerradas detectadas con sensores laterales
if (sl && !s1 && !s2) {
// Curva cerrada izquierda
motorSpeedLeft = MAX_SPEED;
motorSpeedRight = 0;
}

if (sr && !s3 && !s4) {
// Curva cerrada derecha
motorSpeedLeft = 0;
motorSpeedRight = MAX_SPEED;
}

// Aplicar velocidades a los motores analogWrite(MOTOR_LEFT, motorSpeedLeft); analogWrite(MOTOR_RIGHT, motorSpeedRight);

delay(10); // pausa para estabilidad
}

### 9. Repositorio del proyecto

Todo el código fuente, esquemas electrónicos y documentación adicional de este proyecto están disponibles en el siguiente repositorio de GitHub:

Referencia

1. Fernández, Hernán Gustavo (2025). Robot seguidor de línea con Arduino Nano. GitHub: https://github.com/gustavofernandez/Robot-seguidor-de-linea

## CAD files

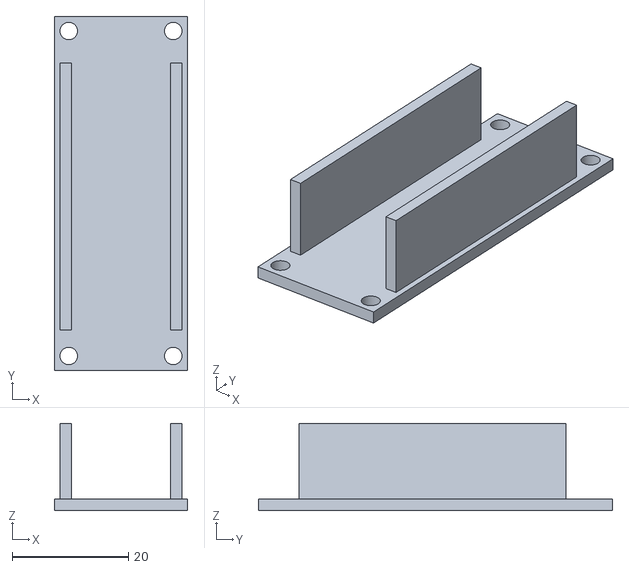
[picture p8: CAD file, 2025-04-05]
Impresion 3D/Robot Soporte Bateria.stl
23.0 x 61.0 x 15.0

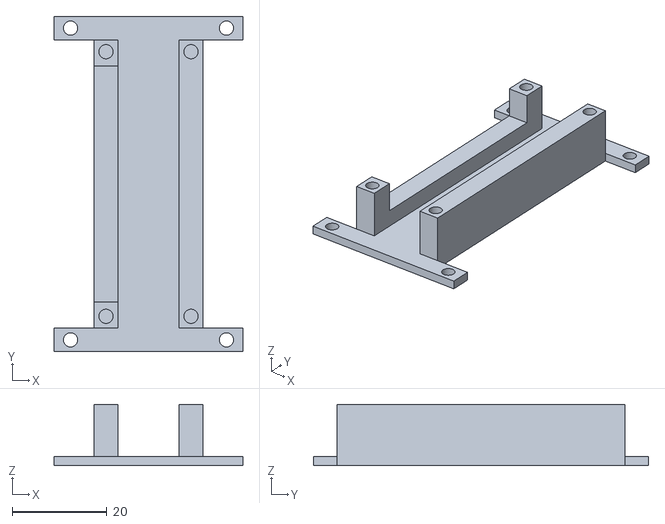
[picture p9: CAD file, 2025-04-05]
Impresion 3D/Robot Soporte Motores.stl
40.0 x 71.0 x 13.0

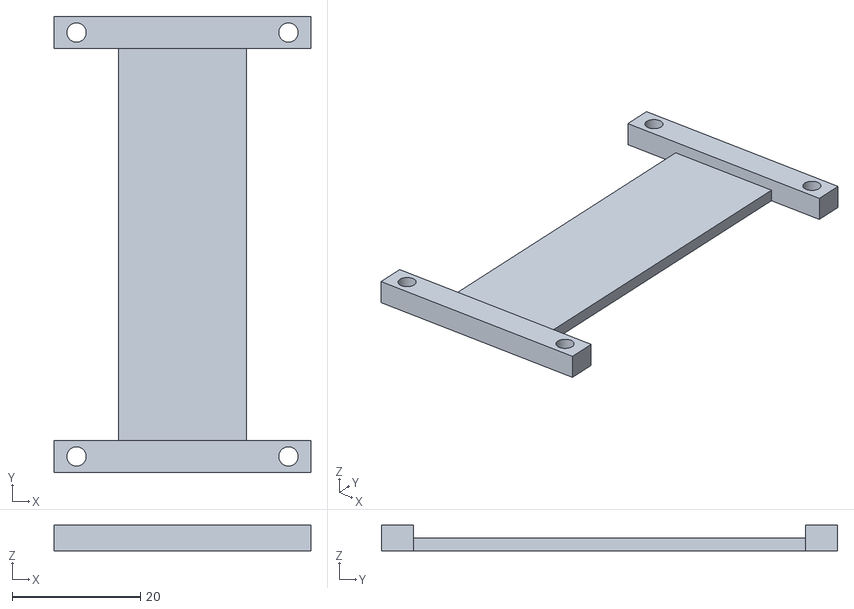
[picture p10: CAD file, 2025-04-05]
Impresion 3D/Robot Soporte Inferior.stl
40.0 x 71.0 x 4.00

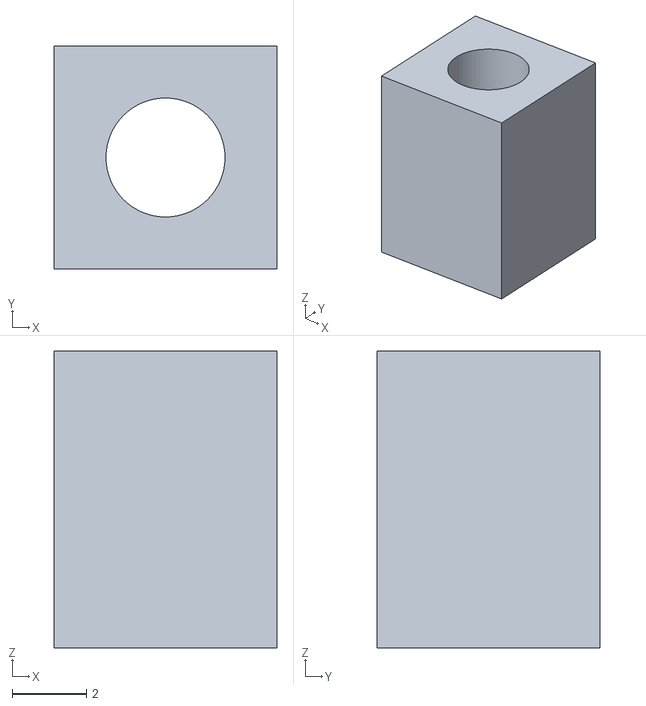
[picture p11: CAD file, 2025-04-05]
Impresion 3D/Robot Soporte Delantero.stl
6.00 x 6.00 x 8.00

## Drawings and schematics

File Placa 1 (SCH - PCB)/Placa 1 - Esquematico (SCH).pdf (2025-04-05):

## GND

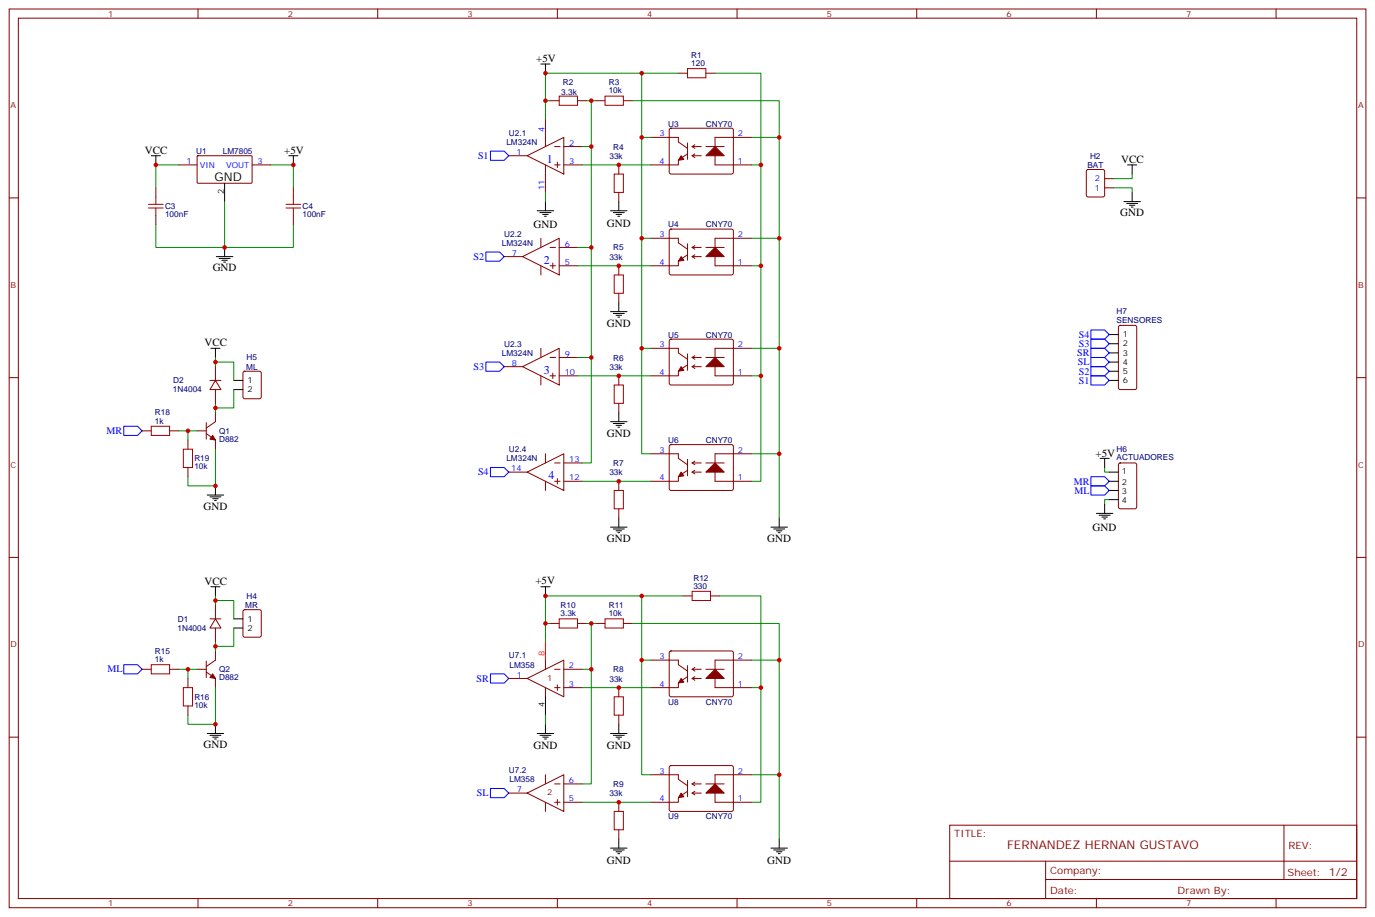
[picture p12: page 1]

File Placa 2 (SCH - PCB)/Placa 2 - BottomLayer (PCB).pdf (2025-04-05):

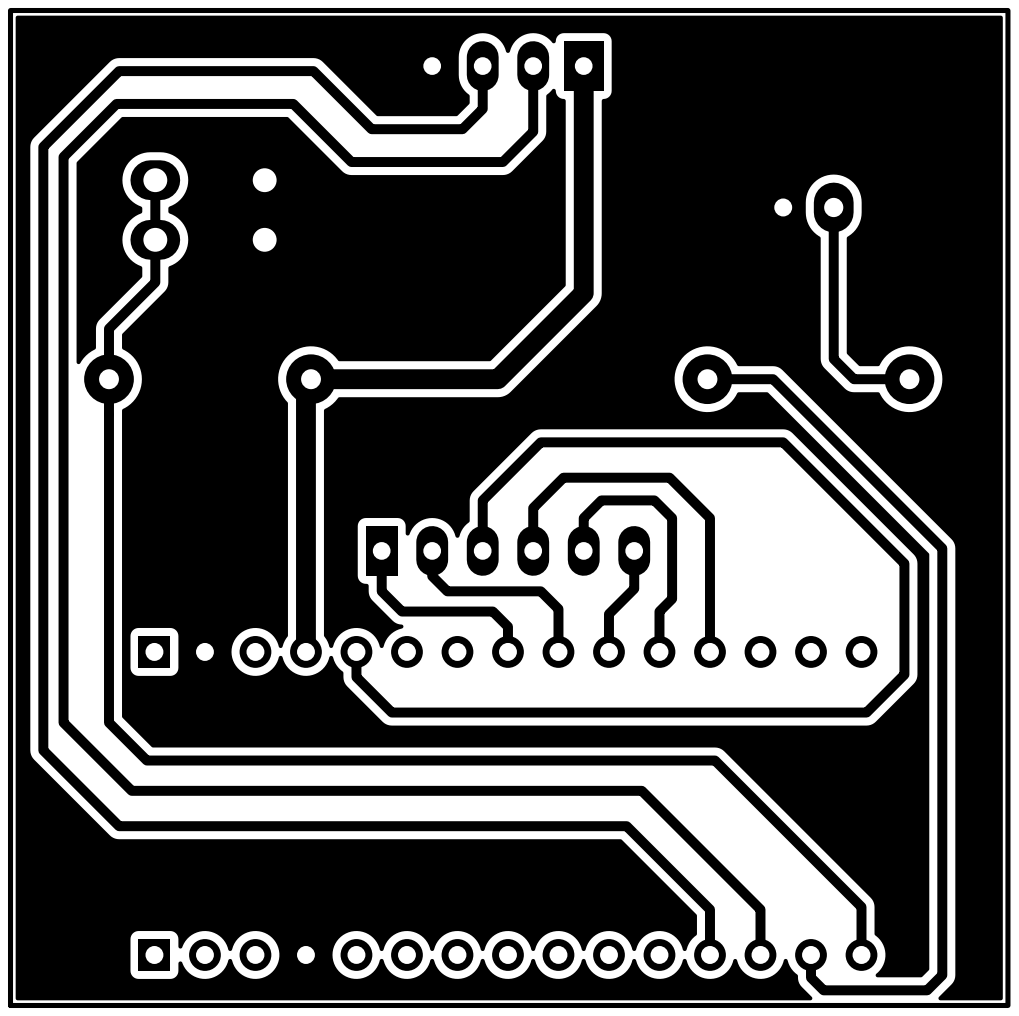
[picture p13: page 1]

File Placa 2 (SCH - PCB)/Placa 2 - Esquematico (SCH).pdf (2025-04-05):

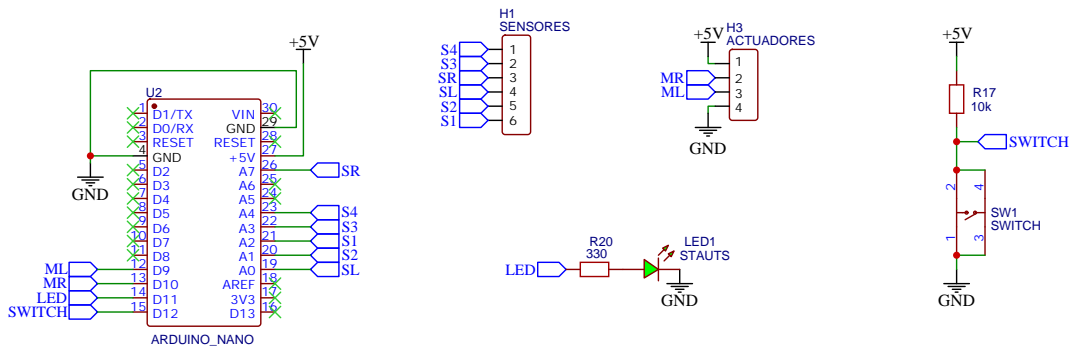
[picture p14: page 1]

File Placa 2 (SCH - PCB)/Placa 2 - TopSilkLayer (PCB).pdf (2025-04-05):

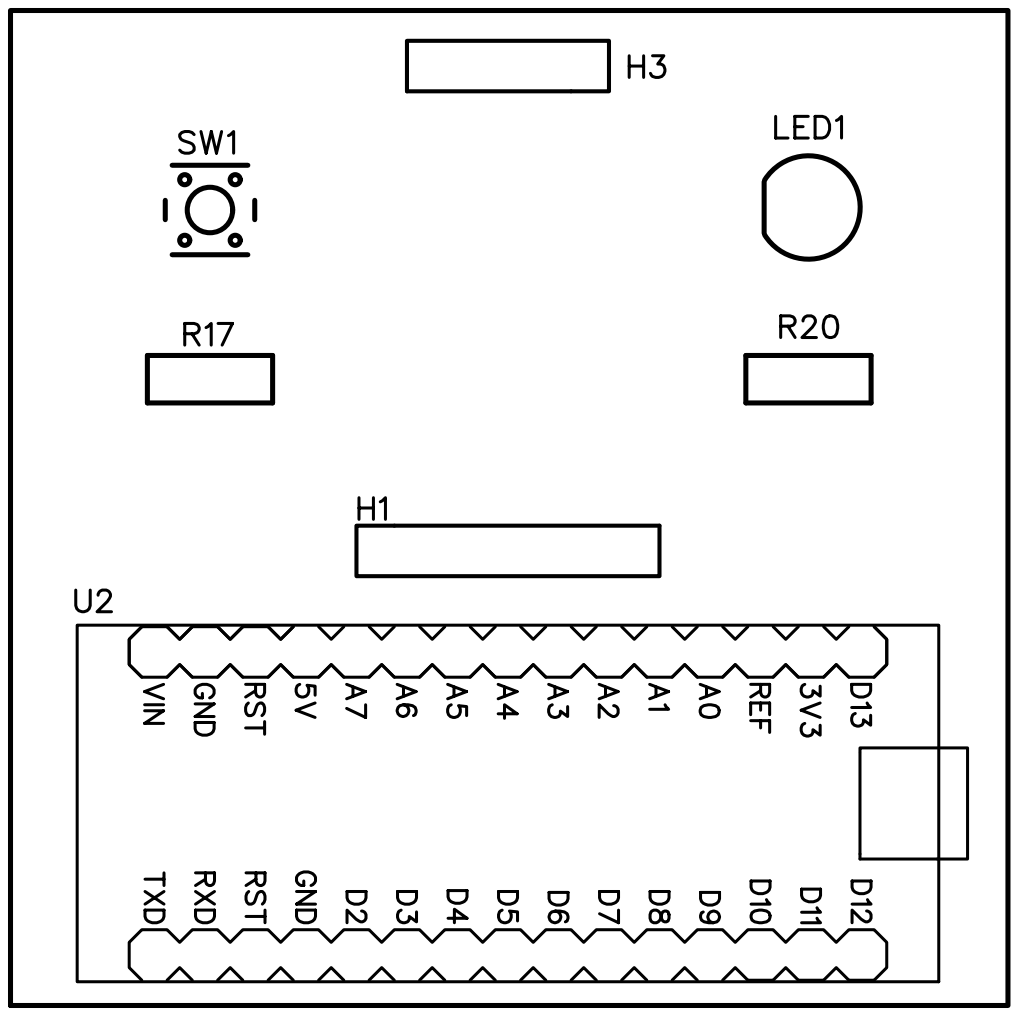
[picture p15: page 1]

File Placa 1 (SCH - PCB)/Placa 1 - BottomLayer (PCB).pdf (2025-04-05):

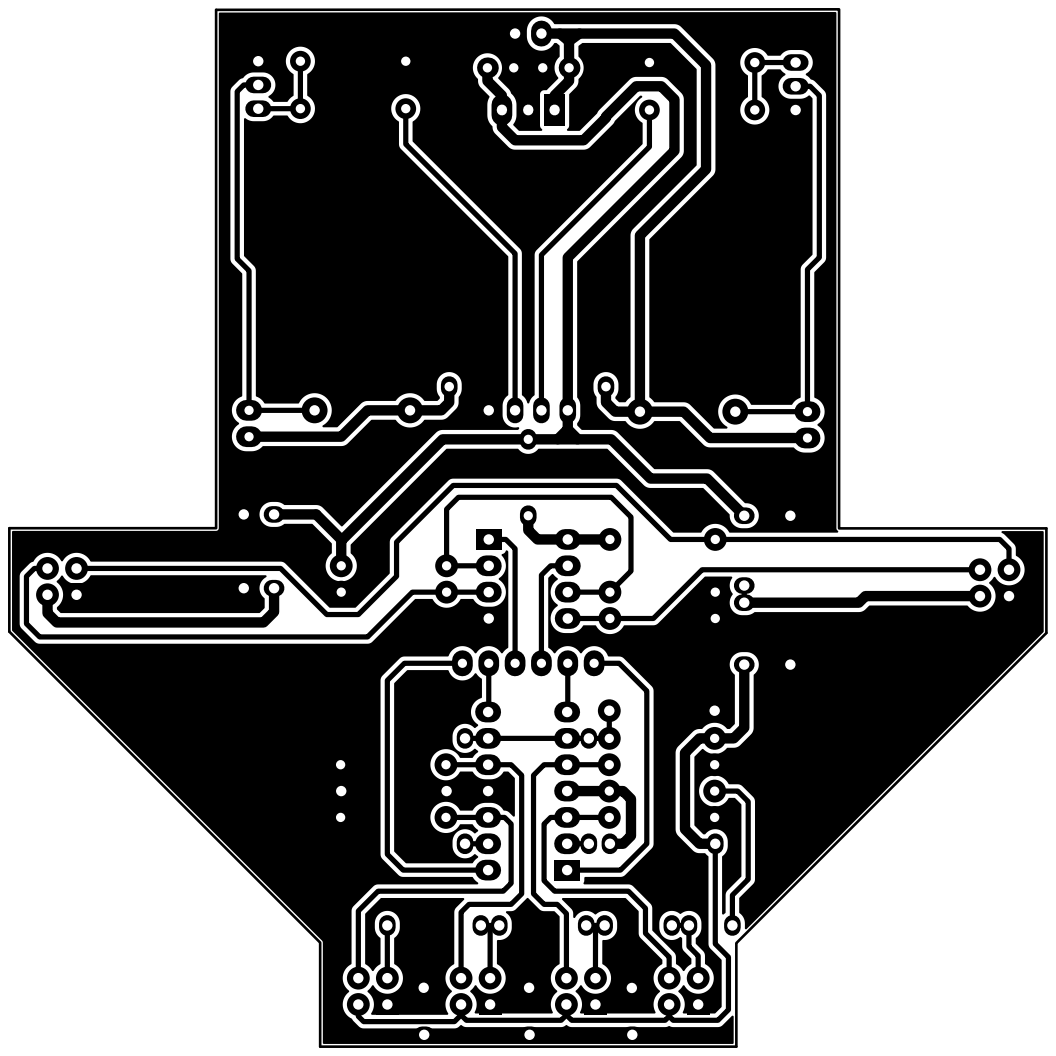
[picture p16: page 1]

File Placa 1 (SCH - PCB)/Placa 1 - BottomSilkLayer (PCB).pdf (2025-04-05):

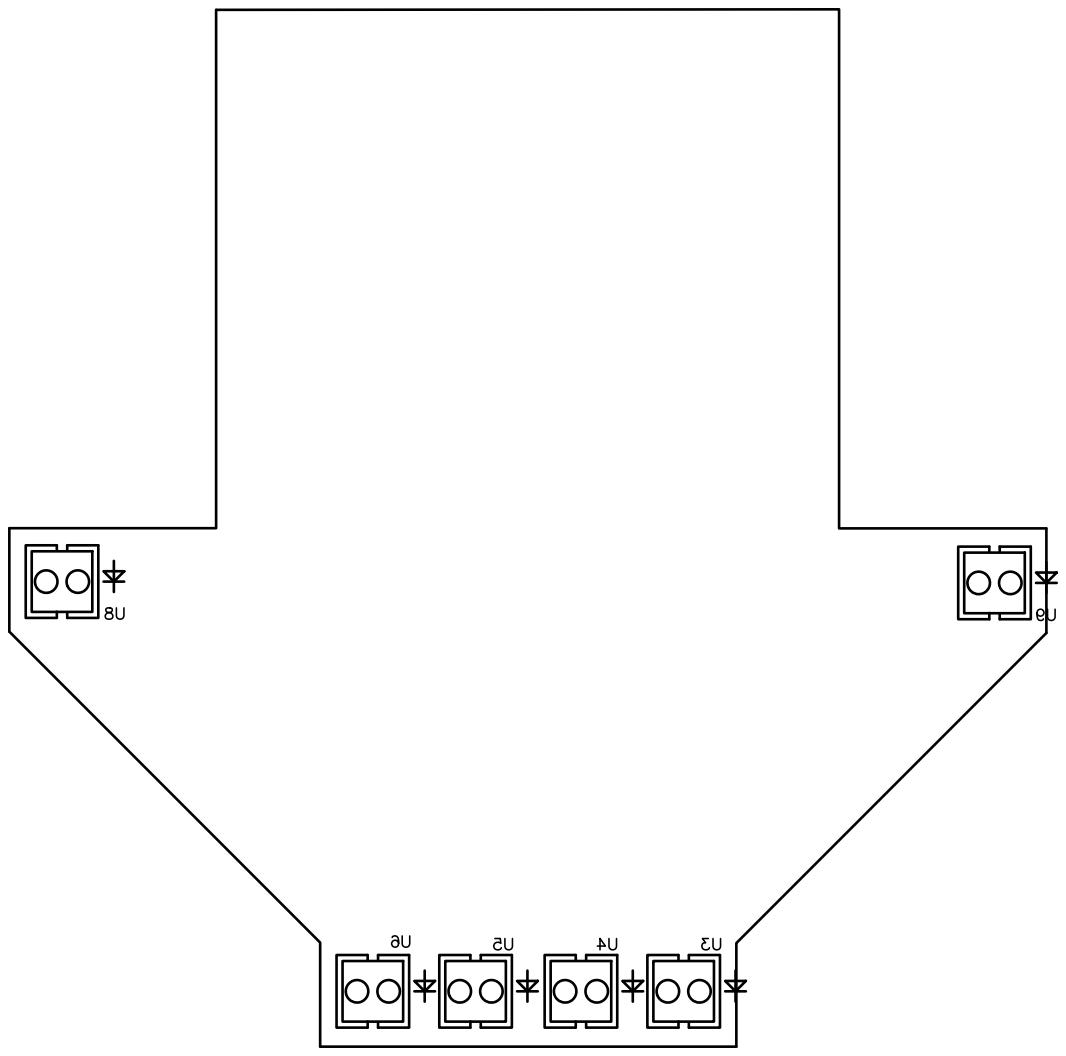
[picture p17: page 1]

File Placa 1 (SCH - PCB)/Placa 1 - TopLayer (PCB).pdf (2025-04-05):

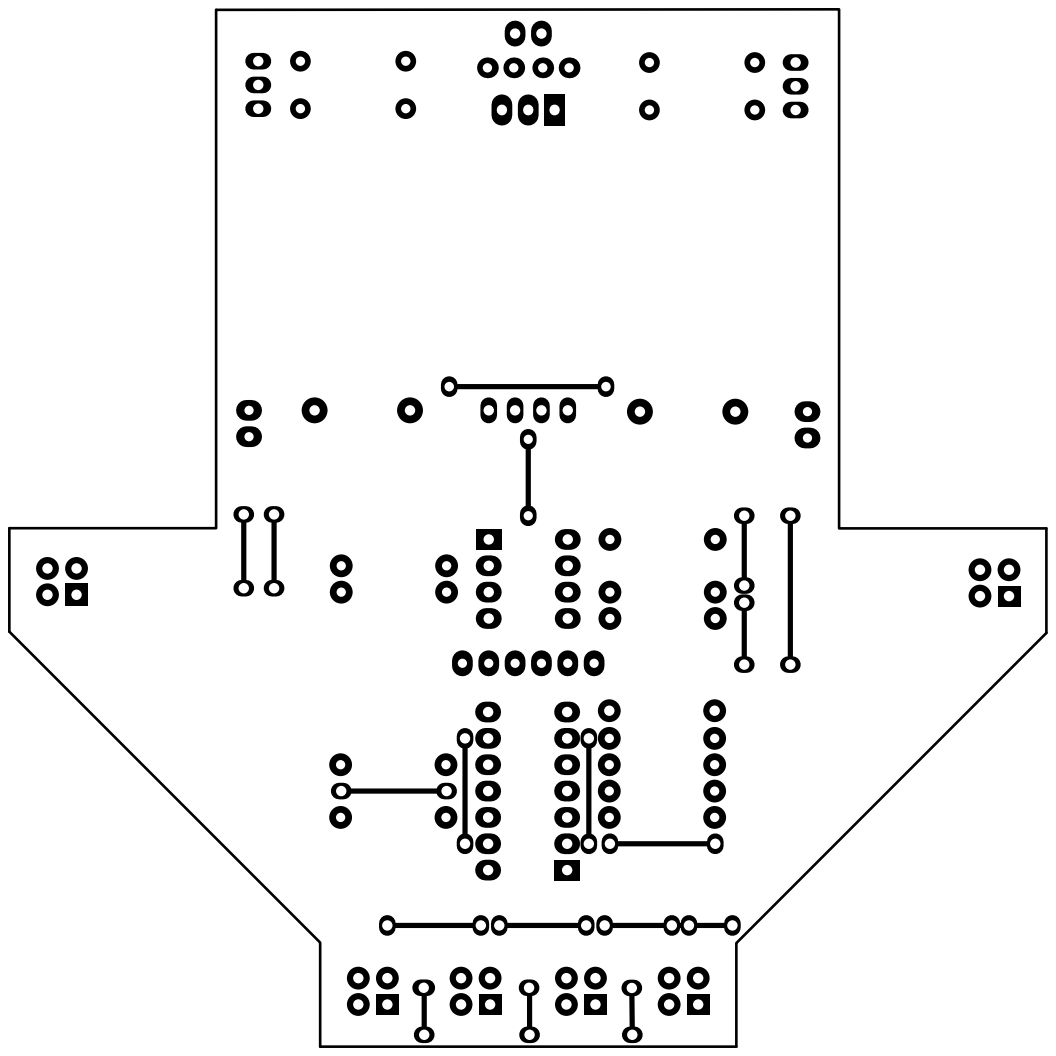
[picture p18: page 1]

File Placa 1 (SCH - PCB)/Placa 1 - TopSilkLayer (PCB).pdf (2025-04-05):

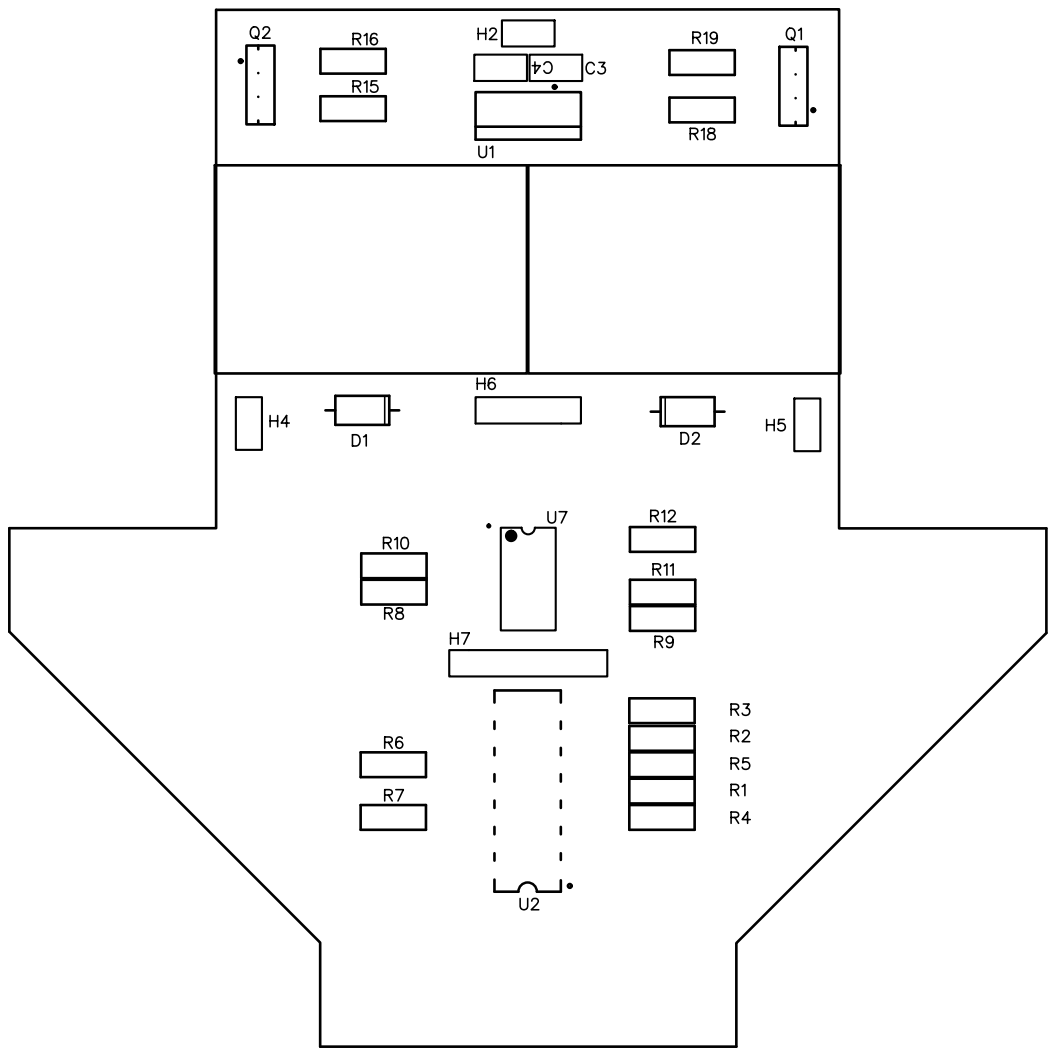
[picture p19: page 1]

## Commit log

2025-04-05 Create Placa 1 (SCH & PCB)
2025-04-05 Create Placa 2 (SCH & PCB)
